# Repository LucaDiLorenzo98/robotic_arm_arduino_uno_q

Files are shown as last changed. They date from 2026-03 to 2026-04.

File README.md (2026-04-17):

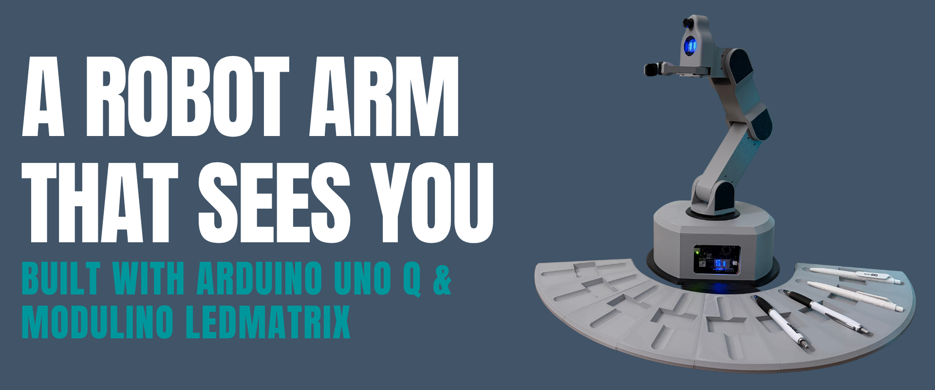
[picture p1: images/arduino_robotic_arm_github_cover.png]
Arduino Robotic Arm Cover


# A Robot Arm That Sees You — Built with Arduino UNO Q & Modulino LedMatrix

A robot arm that recognizes people and delivers gadgets to them — no buttons, no commands, just interaction. Built with the new Arduino UNO Q 4GB and the new Modulino LedMatrix, which gives the robot its friendly face. The arm runs on Feetech digital servo motors with a Waveshare control board, and a camera on the head handles the recognition. From high school tinkering to projects like this — this is what Arduino made possible for me.

---

## Assembly Tutorial

<div align="center">
  <a href="https://www.youtube.com/watch?v=Ro49ItYjisA" target="_blank">
    Assembly Tutorial
  </a>
</div>

---

## Required Hardware

| Component | Details |
|---|---|
| **Arduino UNO Q** | Main board (MPU + MCU, onboard LED matrix 8×13) |
| **4× servo STS3215** | Half-duplex serial bus, IDs 1–4 |
| **Standard PWM servo** | Gripper on digital pin **D9** |
| **2× pressure sensor** | Analog on **A0** and **A1** |
| **Modulino LED Matrix** | Head display 12×8 (optional but recommended) |
| **Half-duplex adapter** | To connect STS3215 to UNO Q Serial port |

### Pin Scheme

```
D9         → gripper servo signal (PWM)
A0         → pressure sensor 1
A1         → pressure sensor 2
Serial (pins 0 & 1) → STS3215 bus (1 Mbit/s, half-duplex)
Modulino Quick Connector → Modulino LED Matrix (head, I2C)
```

---

## Electrical Schematic

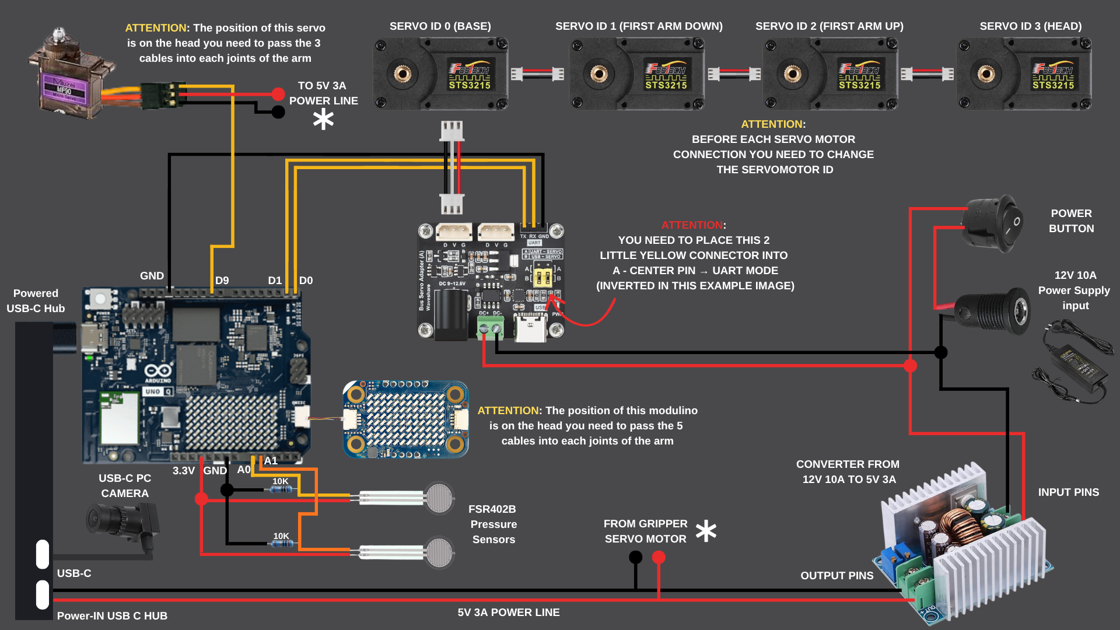
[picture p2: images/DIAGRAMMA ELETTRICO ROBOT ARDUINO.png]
Electrical Schematic Diagram


The schematic above shows the complete electrical connections for the robot, including:
- **Arduino UNO Q** as the main control board
- **STS3215 servo motors** (4×) connected via the Waveshare driver board on the half-duplex serial bus at 1 Mbit/s
- **PWM servo** for gripper control on digital pin D9
- **Pressure sensors** (2×) on analog inputs A0 and A1
- **Power distribution** from a 12V 10A power supply
- **Modulino LED Matrix** connected via I2C on the Quick Connector for the head display

---

## Bill of Materials (Non-Printed Components)

| Component | Qty | Link |
|---|---|---|
| Arduino UNO Q 4GB RAM | 1 | [Buy on Arduino Store](https://store.arduino.cc/products/uno-q-4gb?variant=56485750473079) |
| Modulino LED Matrix | 1 | [Buy on Arduino Store USA](https://store-usa.arduino.cc/products/modulino-led-matrix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) |
| Feetech Digital STS3215 Servo Motors | 4 | [Buy on AliExpress](https://it.aliexpress.com/item/1005009271910382.html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) |
| Waveshare Serial Bus Servo Driver Board | 1 | [Buy on Amazon](https://www.amazon.it/dp/B0CJ6TP3TP?ref=ppx_yo2ov_dt_b_fed_asin_title) |
| Ball Bearing | 1 | [Buy on AliExpress](https://it.aliexpress.com/item/1005009736872307.html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) |
| Pressure Sensors | 2 | [Buy on AliExpress](https://it.aliexpress.com/item/1005009958997279.html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) |
| 12V 10A Power Supply | 1 | [Buy on Amazon](https://www.amazon.it/-/en/dp/B0D1VHNF9R?ref_=ppx_hzsearch_conn_dt_b_fed_asin_title_1) |
| DC Converter 12V to 5V 3A | 1 | [Buy on Amazon](https://www.amazon.it/dp/B08MWK3VKC?ref=ppx_yo2ov_dt_b_fed_asin_title) |
| Lemorele USB-C Docking Station | 1 | [Buy on Amazon](https://www.amazon.it/dp/B08GM2H1Q2?ref=ppx_yo2ov_dt_b_fed_asin_title&th=1) |
| Micro Servo Metal Gear 90° | 1 | [Buy on Amazon](https://www.amazon.it/dp/B0C38H8TBY?ref=ppx_yo2ov_dt_b_fed_asin_title&th=1) |
| USB Camera | 1 | [Buy on Amazon](https://www.amazon.it/dp/B0DNT67G7C?ref=ppx_yo2ov_dt_b_fed_asin_title) |
| Resistors Kit | 1 | Common electronics store |
| M3 Screws | Various | Common hardware store |
| Power Supply Wires | As needed | Common hardware store |
| Power Cable 18/16 AWG | 1 roll | Common hardware store |
| Circular Power Connector | 1 | Common electronics store |
| Circular Switch 2-Pin | 1 | Common electronics store |
| Threaded Inserts (3×4, 5×5 mm) | Set | [Buy on AliExpress](https://it.aliexpress.com/w/wholesale-threaded-inserts-m3.html) |

---

## 3D Files and Printing

3D files are available in the **`3d_models/`** folder:

- **`models.3mf`** – Complete project with all components **already oriented and ready to print** (recommended)
- **Individual STL files** – For those who prefer manual slicing

### Recommended Materials

| Component | Material | Notes |
|---|---|---|
| Arm structure, base, covers | **PETG HF** | Resistant, good rigidity, high temperatures |
| Gripper components (gripper_*) | **TPU 95A** | Elastic, shock-absorbing, suitable for repeated movements |

---

## ⚠️ Pre-Assembly: Servo ID Configuration (MANDATORY)

> **This step must be completed BEFORE assembling the robot.**
> If you skip it, the firmware won't be able to address the servos and nothing will work.

Each STS3215 servo ships from the factory with **ID 1**. Since all 4 motors share the same serial bus, each one must have a unique ID (1, 2, 3, 4) before they are wired together. You must configure them **one at a time**, while they are still unassembled.

### What you need

- The Waveshare Serial Bus Servo Driver Board
- One STS3215 servo connected to it (just one at a time)
- A USB cable to power/connect the board
- The sketch `sc_servo_change_id/sc_servo_change_id.ino` from this repo

### Procedure (repeat for each of the 4 servos)

1. **Connect only one servo** to the Waveshare board. Do not connect the others.
2. Open `sc_servo_change_id/sc_servo_change_id.ino` in Arduino IDE.
3. At the top of the sketch, set the two ID variables:

   ```cpp
   int idAttuale = 1;  // Factory default for a brand-new servo is always 1
   int idNuovo   = 1;  // The ID you want to assign to this servo
   ```

   | Servo | `idAttuale` | `idNuovo` |
   |---|---|---|
   | 1st servo | `1` | `1` |
   | 2nd servo | `1` | `2` |
   | 3rd servo | `1` | `3` |
   | 4th servo | `1` | `4` |

4. Upload and run the sketch. Open the **Serial Monitor** at 115200 baud.
5. If successful, you'll see:
   ```
   SUCCESSO! Il servo ora ha l'ID: X
   Ora puoi scollegarlo e passare al prossimo.
   ```
6. **Disconnect** the servo, connect the next one, update `idNuovo` in the sketch, and repeat.

> If the Serial Monitor shows `ERRORE: Servo non rilevato`, check the 12V power supply to the Waveshare board and verify the connection to the servo. Make sure `idAttuale` matches the servo's current ID (new servos always start at 1).

Once all 4 servos have their IDs assigned, you can proceed with mechanical assembly and wire them all together on the bus.

---

## Arduino Libraries to Install

Open **Tools → Manage Libraries** in Arduino IDE / Arduino Lab and install:

| Library | Min version | Notes |
|---|---|---|
| `Arduino_RouterBridge` | latest | Bridge MCU↔MPU |
| `SCServo` | latest | STS3215 control |
| `Arduino_LED_Matrix` | latest | Onboard UNO Q matrix |
| `ArduinoGraphics` | latest | LED Matrix dependency |
| `Modulino` or `Arduino_Modulino` | latest | For LED head (optional) |

---

## Python Dependencies

The project runs on the MPU (Linux) side of UNO Q via Arduino Python environment. No manual installation required: the dependencies (`arduino.app_utils`, `arduino.app_bricks.video_objectdetection`) are part of the Arduino SDK.

Only standard libraries are used: `datetime`, `time`, `threading`, `math`, `os`, `sys`, `functools`.

---

## How to Upload and Run

1. Open **Arduino Lab** (or Arduino IDE with UNO Q support).
2. Upload the sketch `sketch/sketch.ino` to the board.
3. The Python app `python/main.py` is automatically started by the Arduino environment on the MPU side.
4. Real-time logs are also written to `python/robot.log` (with timestamp).

---

## Robot Setup (First Power-On or Reset)

On startup, the robot automatically enters **setup mode**. The onboard matrix shows the current step (**S1**, **S2**, **S3**).

STS3215 servo torque is **disabled**: you can move the arm freely by hand.

### Step S1 – HOME Position

1. Move the arm by hand to the HOME position (upright, centered).
2. Hold it steady for **5 seconds** → the matrix blinks the step number during the countdown.
3. Once captured, the robot nods with servo 4 to confirm, then moves to S2.

### Step S2 – Slot Positions (up to 9)

1. Move the arm toward the **first slot** (where the pens are).
2. Hold it steady for **5 seconds** → slot captured, the robot returns to HOME and nods.
3. Repeat for each following slot (up to a maximum of **9 slots**).
4. After the last slot, the robot returns to HOME and shows **S3** → setup complete.

> The system ignores small vibrations and microadjustments: it waits for real manual movement before starting the countdown.

### Step S3 – Setup Complete

The robot enters **detect** state and is operational.

---

## Normal Operation

```
setup → detect → grab → delivery → (face detected) → release → detect → ...
```

| State | What it does | Display |
|---|---|---|
| **detect** | Awaits face detection; idle animation on servos | Blinking eyes, matrix **D** |
| **grab** | Collects pen from current slot (base rotation → descent → gripper close → HOME) | Fixed eyes, matrix **G** |
| **delivery_waiting** | Waits at HOME with pen in hand for a face to arrive | Fixed eyes |
| **release** | Detects face → shows hearts, opens gripper, delivers pen | Heart eyes, matrix **R** |

### Grab Cycle Details

1. Base rotation toward slot
2. Partial descent (50% travel)
3. Gripper soft open (~165°)
4. Full descent to slot
5. Gripper close (180° × 3 attempts)
6. Return to HOME
7. Wait for face for delivery

Pressure sensors on A0/A1 are read before and after gripper close (log: `[GRAB][PRESSURE]`).

### Idle Animation

When in **detect** state, the arm performs smooth sinusoidal oscillation on all 4 servos (period 10 s), then returns to HOME and stops for 30 s before repeating.

---

## Error Codes (Onboard Display)

| Display | Code | Cause |
|---|---|---|
| `ER1` | Setup pose unavailable | One or more STS3215 don't respond to ping during setup |
| `ER2` | Grab slot not configured | Grab requested but no slot configured |
| `ER3` | STS move failed | STS movement command failed |
| `ER4` | *(deprecated)* | Matrix unavailable |
| `ER5` | Pressure read failed | Pressure sensor read error |

---

## Logging and Debug

- Logs are written to both console and `python/robot.log` (each line has timestamp `HH:MM:SS.mmm`).
- You can set a custom path with the `ROBOT_LOG_PATH` environment variable.
- STS3215 logs show ping and position of each servo on startup (`[STS3215] Check servo`).

---

## Project Structure

```
sketch/
  sketch.ino         # Arduino firmware (MCU): servo, STS3215, LED matrix, Bridge
python/
  main.py            # Python app (MPU): face detection, state machine, idle animation
  robot.log          # Runtime log (auto-generated)
images/
  arduino_robotic_arm_github_cover.png
```

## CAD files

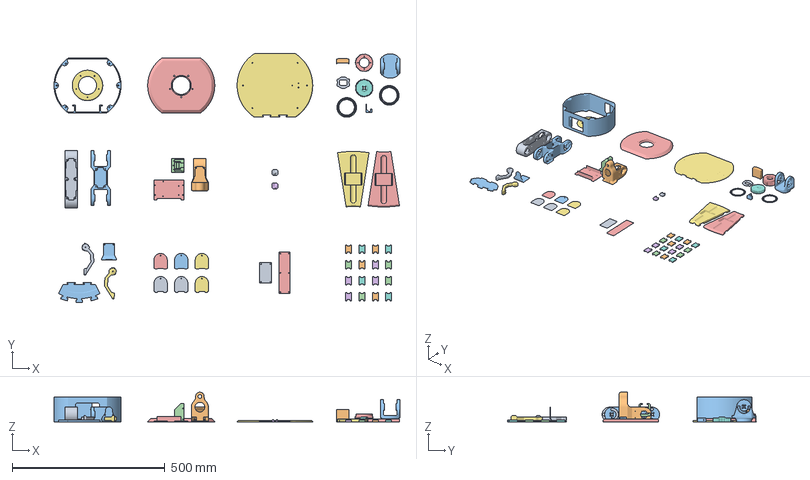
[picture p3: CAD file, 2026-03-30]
3d_models/arduino_robot_gadget_3d_model.3mf
1134.3 x 814.8 x 97.2 mm
gripper_pen_threated_pad_dx.stl
third_arm.stl
third_arm_cover.stl
servo_base_support.stl
arduino_support_shield.stl
gripper_pen_threated_pad_sx.stl
free_gripper.stl
pen_holder_joint.stl x 16
servo_gripper.stl
holders_base_connector.stl
first_arm_cover.stl
joint_cover.stl x 6
second_arm_cover.stl
pen_holder.stl x 2
first_arm_joint.stl
second_arm.stl
first_arm_gear.stl
base_cover.stl
servo_gear.stl
first_arm.stl
outer_spacer.stl x 2
base_side.stl
base_top.stl
inner_spacer.stl x 2
bearing_cover.stl
modulino_led_matrix_support.stl
servo_support_enforcer.stl
third_arm_gear_support.stl

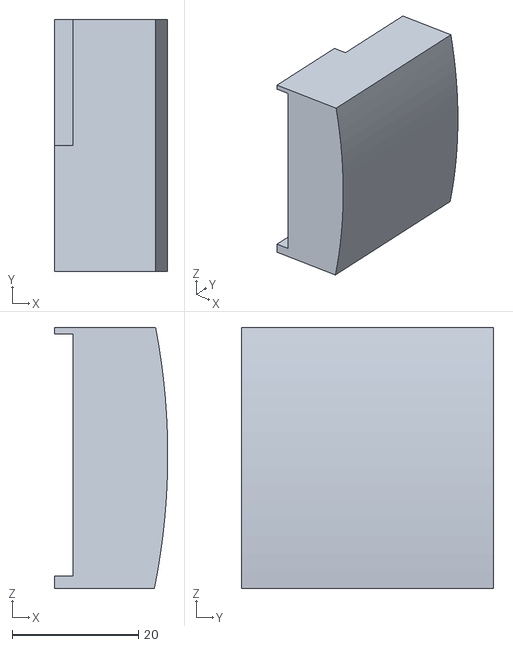
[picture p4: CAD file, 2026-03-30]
3d_models/STLs/servo_support_enforcer.stl
18.0 x 40.0 x 41.4

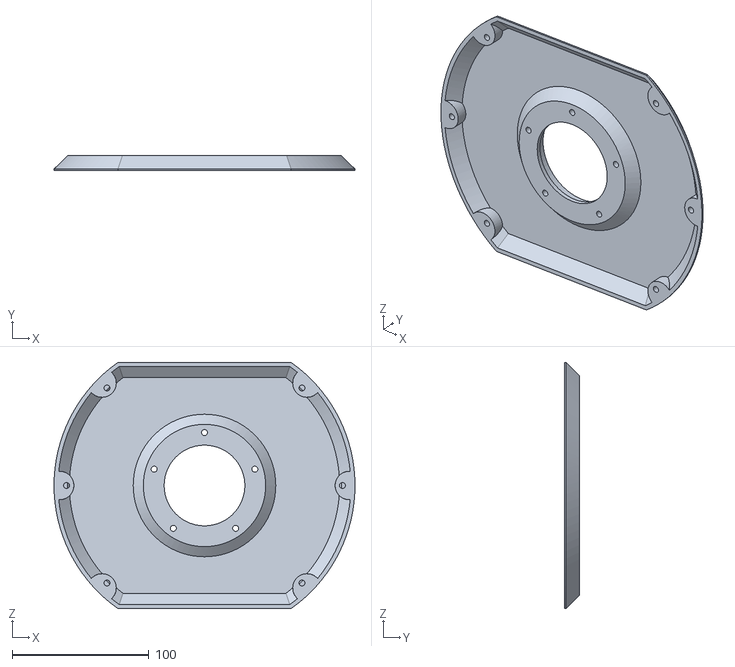
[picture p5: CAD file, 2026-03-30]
3d_models/STLs/base_top.stl
220.0 x 11.2 x 180.0

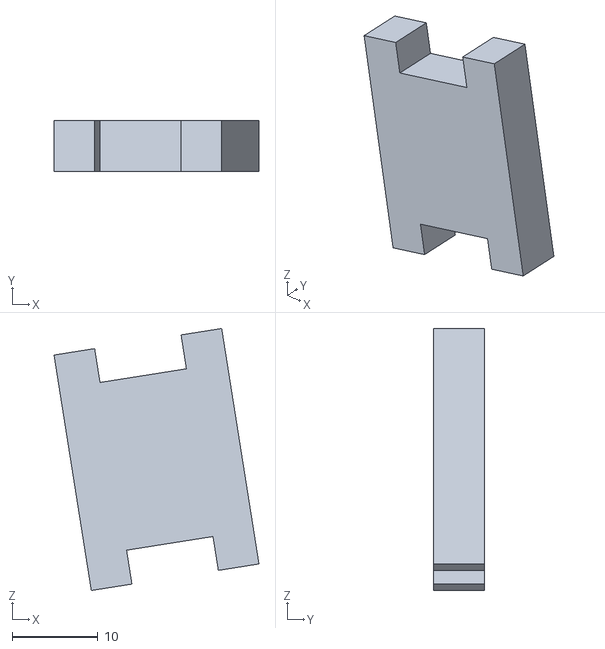
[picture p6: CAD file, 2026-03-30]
3d_models/STLs/pen_holder_joint.stl
23.9 x 5.90 x 30.6

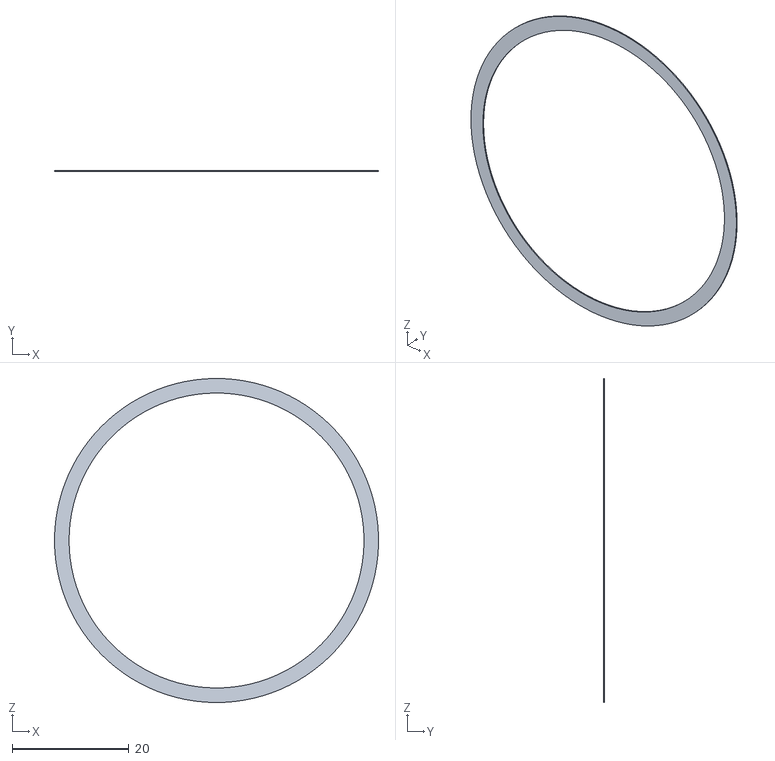
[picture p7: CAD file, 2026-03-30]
3d_models/STLs/inner_spacer.stl
55.6 x 0.2 x 55.6

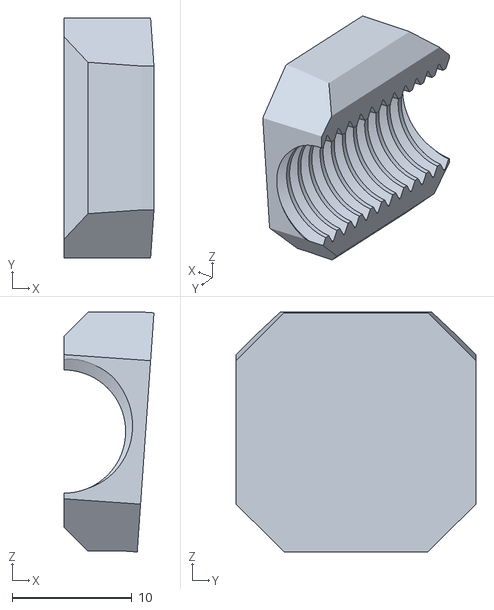
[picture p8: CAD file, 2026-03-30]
3d_models/STLs/gripper_pen_threated_pad_dx.stl
7.50 x 20.0 x 20.0

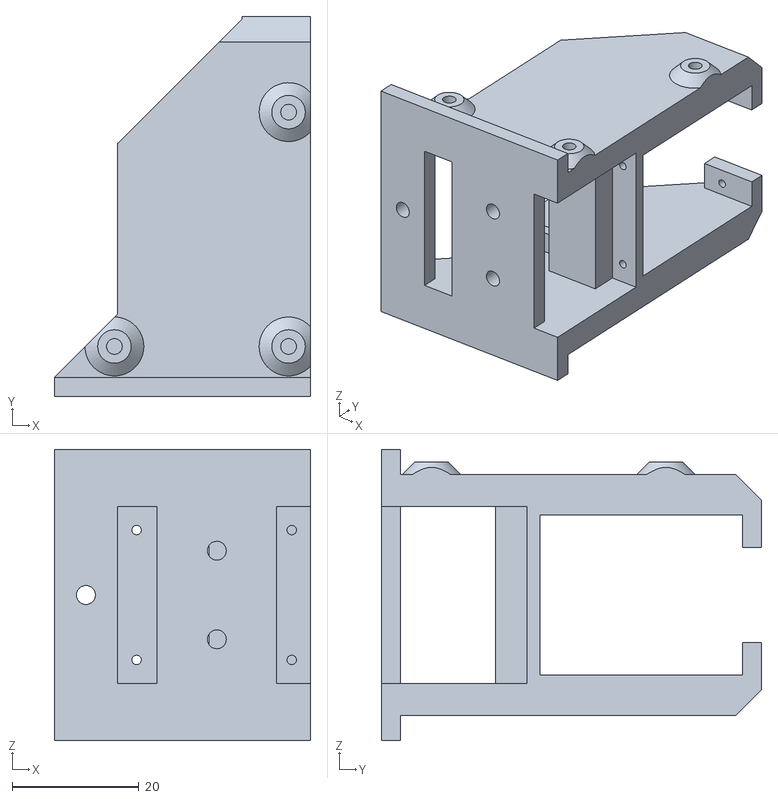
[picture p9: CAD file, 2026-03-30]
3d_models/STLs/servo_base_support.stl
40.5 x 60.0 x 46.0

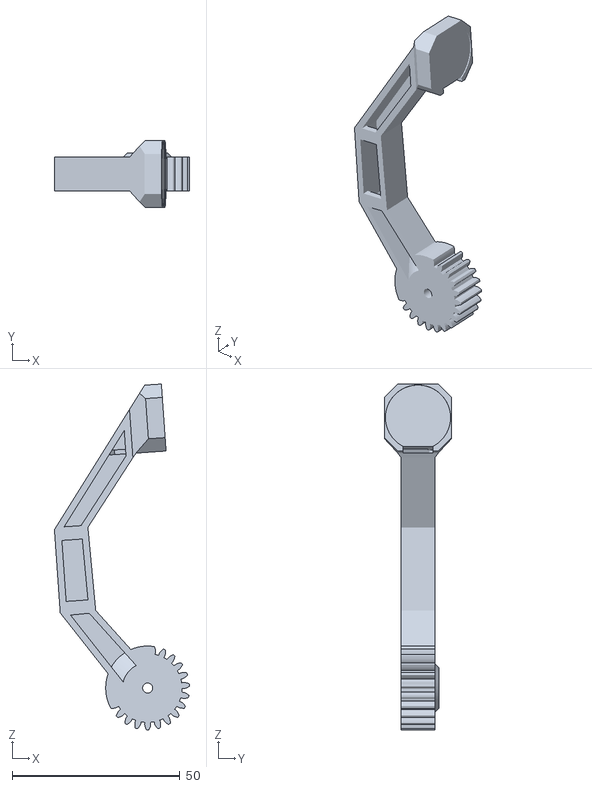
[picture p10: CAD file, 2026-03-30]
3d_models/STLs/free_gripper.stl
40.2 x 20.0 x 103.0

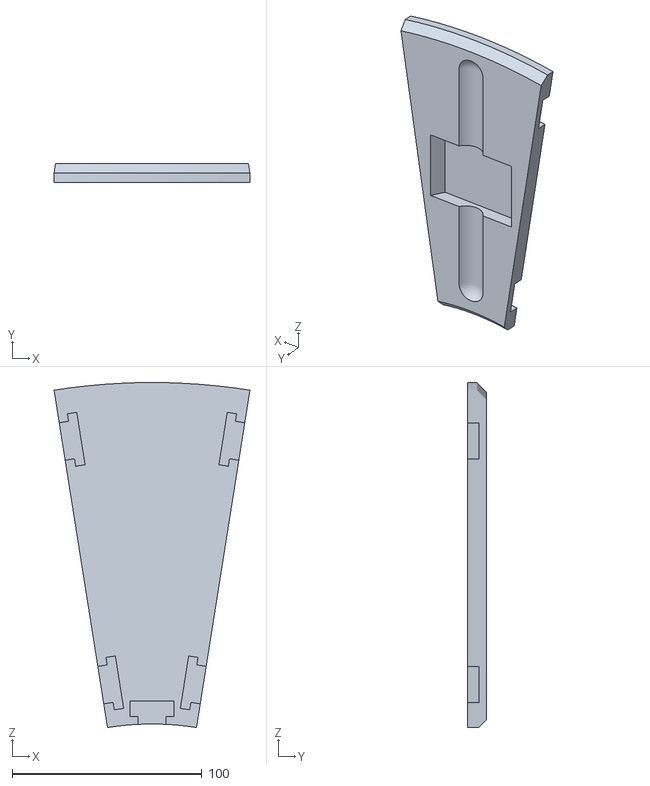
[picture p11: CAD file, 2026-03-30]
3d_models/STLs/pen_holder.stl
103.2 x 10.0 x 181.8

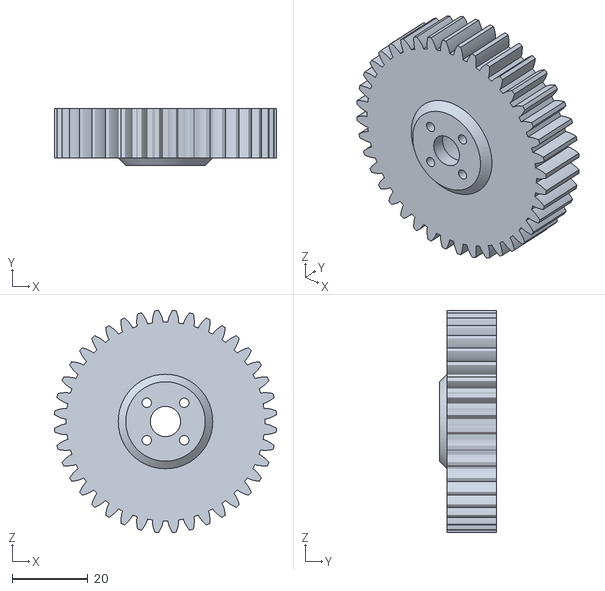
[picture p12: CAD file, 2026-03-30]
3d_models/STLs/servo_gear.stl
58.7 x 15.0 x 58.7

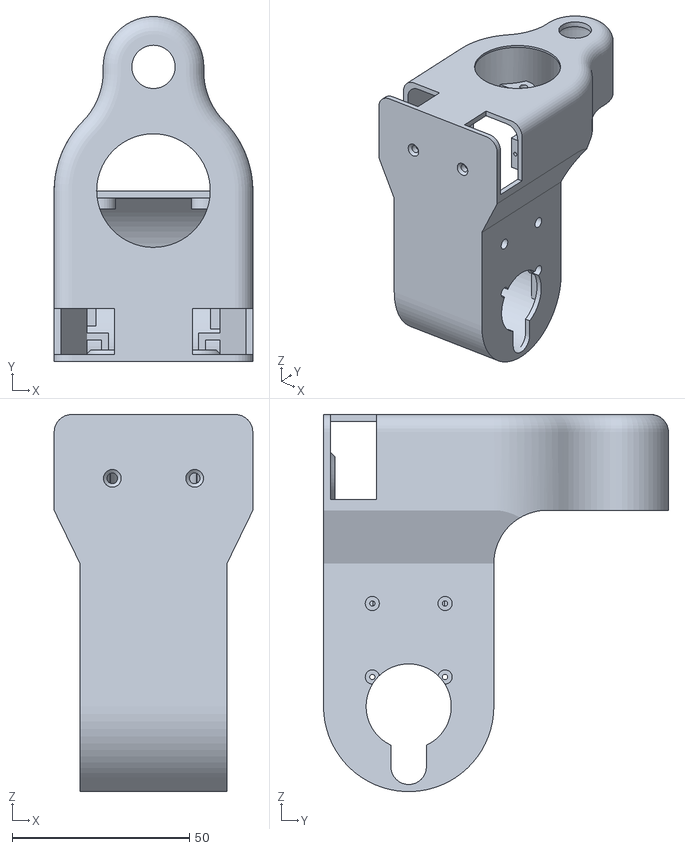
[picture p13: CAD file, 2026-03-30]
3d_models/STLs/third_arm.stl
56.0 x 97.2 x 106.2

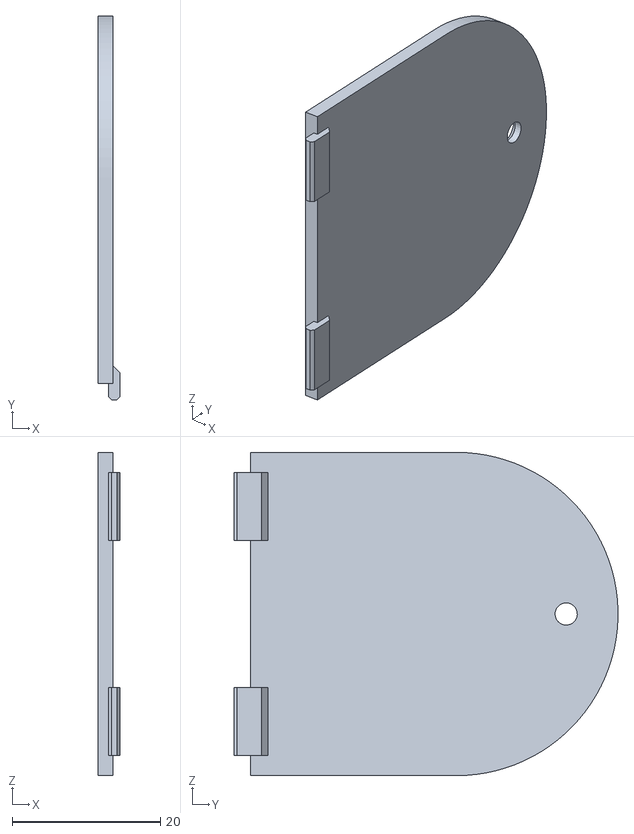
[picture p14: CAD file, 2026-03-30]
3d_models/STLs/joint_cover.stl
2.90 x 51.8 x 43.6

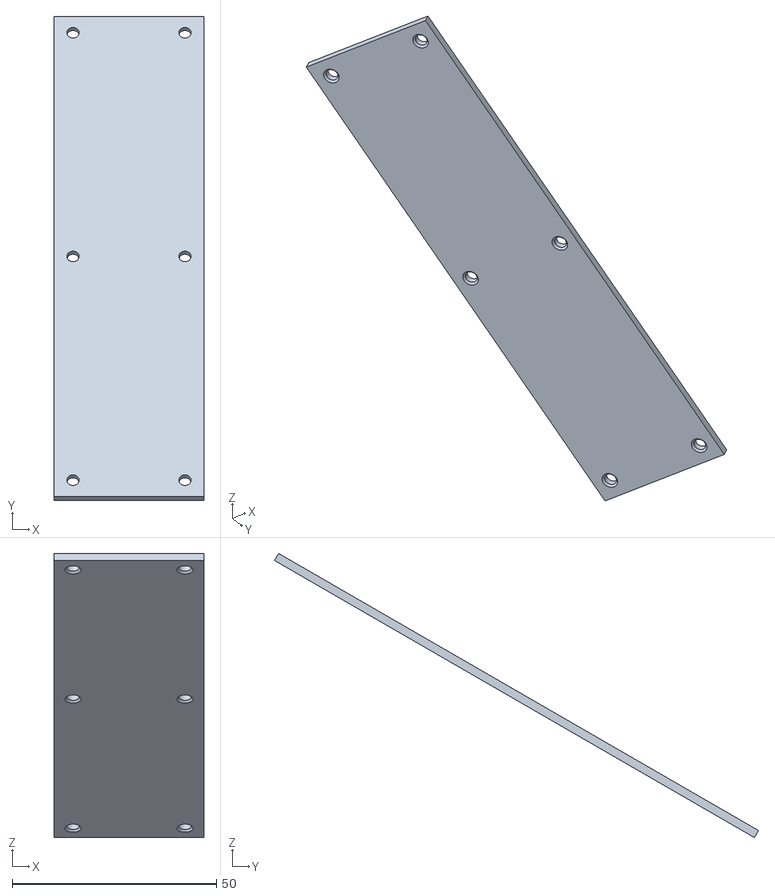
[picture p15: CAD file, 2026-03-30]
3d_models/STLs/first_arm_cover.stl
36.6 x 118.4 x 69.5

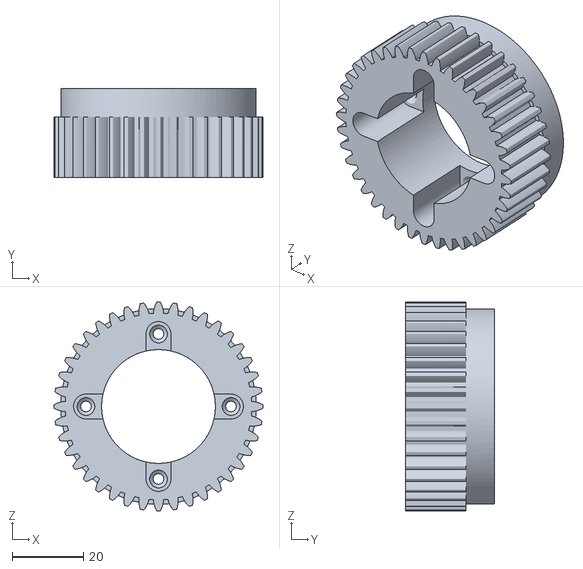
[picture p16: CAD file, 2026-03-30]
3d_models/STLs/first_arm_gear.stl
58.8 x 25.0 x 58.8

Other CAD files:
3d_models/STLs/gripper_pen_threated_pad_sx.stl
3d_models/STLs/third_arm_cover.stl
3d_models/STLs/outer_spacer.stl
3d_models/STLs/bearing_cover.stl
3d_models/STLs/arduino_support_shield.stl
3d_models/STLs/base_cover.stl
3d_models/STLs/base_side.stl
3d_models/STLs/first_arm.stl
3d_models/STLs/first_arm_joint.stl
3d_models/STLs/holders_base_connector.stl
3d_models/STLs/modulino_led_matrix_support.stl
3d_models/STLs/second_arm.stl
3d_models/STLs/second_arm_cover.stl
3d_models/STLs/servo_gripper.stl
3d_models/STLs/third_arm_gear_support.stl

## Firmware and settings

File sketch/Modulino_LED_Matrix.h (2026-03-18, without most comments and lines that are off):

#pragma once
#include "Arduino.h"
#include "Wire.h"
#if __has_include("ArduinoGraphics.h")
#include <ArduinoGraphics.h>
#define MATRIX_WITH_ARDUINOGRAPHICS
#endif
#if defined(ARDUINO_UNOR4_WIFI) || defined(ARDUINO_NANO_R4) || defined(ARDUINO_UNO_Q)
#define DEFAULT_WIRE Wire1
#else
#define DEFAULT_WIRE Wire
#endif
constexpr uint8_t NUM_LEDS = 96;
constexpr uint8_t DEFAULT_ADDRESS = 0x39;
constexpr uint8_t GRAYSCALE_FRAME_SIZE = 48;
constexpr uint8_t MONOCHROMATIC_FRAME_SIZE = 12;
constexpr size_t DURATION_SIZE = sizeof(uint32_t);
constexpr size_t MONOCHROMATIC_ANIMATION_FRAME_SIZE = MONOCHROMATIC_FRAME_SIZE + DURATION_SIZE;
constexpr char GRAYSCALE_IDENTIFIER[] = "GS4";
constexpr char MONOCHROMATIC_IDENTIFIER[] = "MON";
constexpr uint8_t MODE_IDENTIFIER_SIZE = 3;
enum class DisplayMode {
    MonochromaticVertical,
    MonochromaticHorizontal,
    Grayscale,
    Default = MonochromaticVertical
};
class ModulinoLEDMatrix
#ifdef MATRIX_WITH_ARDUINOGRAPHICS
    : public ArduinoGraphics
#endif
     {
public:
    ModulinoLEDMatrix(uint8_t address = DEFAULT_ADDRESS, HardwareI2C& wire = DEFAULT_WIRE, DisplayMode mode = DisplayMode::Default)
    #ifdef MATRIX_WITH_ARDUINOGRAPHICS
        : ArduinoGraphics(canvasWidth, canvasHeight)
    #endif
    {
        _address = address;
        _wire = &wire;
        _mode = mode;
    }
    ModulinoLEDMatrix(HardwareI2C& wire, uint8_t address = DEFAULT_ADDRESS, DisplayMode mode = DisplayMode::Default)
    #ifdef MATRIX_WITH_ARDUINOGRAPHICS
        : ArduinoGraphics(canvasWidth, canvasHeight)
    #endif
    {
        _address = address;
        _wire = &wire;
        _mode = mode;
    }
    void setMode(DisplayMode mode){
        _mode = mode;
        sendMode();
    }
    int begin() {
        if (_initialized) {
            return 1; // Already initialized
        }
        _wire->begin();
        _initialized = true;
        sendMode();
        return 1;
    }
    void nextFrame() {
        renderFrame();
        _currentFrameNumber = (_currentFrameNumber + 1) % _framesCount;
        if(_currentFrameNumber == 0){
            _sequenceDone = true;
            if(_sequenceDoneCallBack != nullptr){
                _sequenceDoneCallBack();
            }
        }
    }
    template<size_t N>
    void setFrame(const uint32_t(&buffer)[N]){
        size_t frameSize = expectedFrameSize();
        uint8_t data[frameSize];
        convert32to8bit(buffer, N, data, frameSize);
        prepareFrame(data);
        sendFrame(data, frameSize);
    }
    template<size_t N>
    void setFrame(const uint8_t(&buffer)[N]){
        size_t frameSize = expectedFrameSize();
        uint8_t data[frameSize];
        auto length = (N < frameSize) ? N : frameSize;
        memcpy(data, buffer, length);
        prepareFrame(data);
        sendFrame(data, length);
    }
    void renderFrame(uint32_t frameNumber){
        _currentFrameNumber = frameNumber % _framesCount;
        renderFrame();
    }
    void renderFrame(){
        size_t frameSize = expectedFrameSize();
        uint8_t data[frameSize];
        getCurrentFrameData(data);
        setCurrentDuration();
        prepareFrame(data);
        sendFrame(data, frameSize);
    }
    void play(bool looping = false){
        _loop = looping;
        _sequenceDone = false;
        do {
            nextFrame();
            delay(_duration);
            if (_loop && _sequenceDone) {
                _sequenceDone = false;
            }
        } while (_sequenceDone == false);
    }
    uint32_t getCurrentDuration() const {
        return _duration;
    }
    uint32_t getCurrentFrameNumber() const {
        return _currentFrameNumber;
    }
    uint32_t getFrameCount() const {
        return _framesCount;
    }
    void setSequence(const uint8_t* frames, size_t bytes, bool is32Bit = false) {
        _currentFrameNumber = 0;
        _frames = frames;
        size_t frameSize = expectedFrameSize();
        _framesCount = bytes / (frameSize + 4);
        _framesAre32Bit = is32Bit;
    }
    template<size_t N, size_t M>
    void setSequence(const uint32_t (&frames)[N][M]) {
        setSequence((const uint8_t*)frames, sizeof(frames), true);
    }
    template<size_t N, size_t M>
    void setSequence(const uint8_t (&frames)[N][M]) {
        setSequence((const uint8_t*)frames, sizeof(frames));
    }
    template<size_t N, size_t M>
    void setSequence(const uint8_t (&frames)[N][M], size_t usedBytes) {
        setSequence((const uint8_t*)frames, usedBytes);
    }
    void setSequenceDoneCallback(voidFuncPtr callBack){
        _sequenceDoneCallBack = callBack;
    }
    void clear() {
        const uint32_t fullOff[] = {
            0x00000000,
            0x00000000,
            0x00000000
        };
        setFrame(fullOff);
        #ifdef MATRIX_WITH_ARDUINOGRAPHICS
        memset(_canvasBuffer, 0, sizeof(_canvasBuffer));
        #endif
    }
#ifdef MATRIX_WITH_ARDUINOGRAPHICS
    template<size_t N, size_t M>
    void loadPixelsToFrameBuffer(const uint8_t (&pixelData)[N][M], uint8_t* outputFrameBuffer) {
        memset(outputFrameBuffer, 0, (N * M) / 8);
        const uint8_t* pixelDataFlat = &pixelData[0][0];
        size_t index;
        for (size_t i = 0; i < (N * M); i++) {
             if (pixelDataFlat[i]) {
                if (_mode == DisplayMode::MonochromaticHorizontal) {
                    outputFrameBuffer[i / 8] |= (1 << (7 - (i % 8)));
                } else if (_mode == DisplayMode::MonochromaticVertical) {
                    size_t row = i / M;
                    size_t col = i % M;
                    index = col * N + row;
                    outputFrameBuffer[index / 8] |= (1 << (index % 8));
                } else {
                    return; // Unsupported mode for this function
                }
            }
        }
    }
    void renderCanvas(){
        loadPixelsToFrameBuffer(_canvasBuffer, _graphicsFrameHolder);
        setFrame(_graphicsFrameHolder);
    };
    virtual void set(int x, int y, uint8_t r, uint8_t g, uint8_t b) override {
      if (y >= canvasHeight || x >= canvasWidth || y < 0 || x < 0) {
        return;
      }
      _canvasBuffer[y][x] = (r | g | b) > 0 ? 1 : 0;
    }
    void endText(int scrollDirection = NO_SCROLL) {
      ArduinoGraphics::endText(scrollDirection);
      renderCanvas();
    }
    void endDraw() override {
        ArduinoGraphics::endDraw();
        if (!captureAnimation) {
            renderCanvas();
            return;
        }
        if (captureAnimationFrameRemainingBytes >= MONOCHROMATIC_ANIMATION_FRAME_SIZE) {
            loadPixelsToFrameBuffer(_canvasBuffer, captureAnimationFrame);
            uint32_t speed = _textScrollSpeed;
            memcpy(captureAnimationFrame + MONOCHROMATIC_FRAME_SIZE, &speed, DURATION_SIZE);
            captureAnimationFrame += MONOCHROMATIC_ANIMATION_FRAME_SIZE;
            captureAnimationFrameRemainingBytes -= MONOCHROMATIC_ANIMATION_FRAME_SIZE;
        }
    }
    template <size_t N, size_t M>
    void endTextAnimation(int scrollDirection, uint8_t (&frames)[N][M], uint32_t& bytesUsed) {
      captureAnimationFrame = &frames[0][0];
      captureAnimationFrameRemainingBytes = sizeof(frames);
      captureAnimation = true;
      ArduinoGraphics::textScrollSpeed(0);
      ArduinoGraphics::endText(scrollDirection);
      ArduinoGraphics::textScrollSpeed(_textScrollSpeed);
      captureAnimation = false;
      bytesUsed = sizeof(frames) - captureAnimationFrameRemainingBytes;
    }
    void textScrollSpeed(unsigned long speed) override {
      ArduinoGraphics::textScrollSpeed(speed);
      _textScrollSpeed = speed;
    }
  private:
    uint8_t _graphicsFrameHolder[MONOCHROMATIC_FRAME_SIZE]; // 12 bytes
    uint8_t* captureAnimationFrame = nullptr; // pointer to next frame to write
    uint32_t captureAnimationFrameRemainingBytes = 0; // bytes remaining in buffer
    bool captureAnimation = false;
    static const byte canvasWidth = 12;
    static const byte canvasHeight = 8;
    uint8_t _canvasBuffer[canvasHeight][canvasWidth] = {{0}};
    unsigned long _textScrollSpeed = 100;
#endif
private:
    void sendFrame(uint8_t* data, size_t length) {
        if(!_initialized) return;
        _wire->beginTransmission(_address);
        _wire->write(data, length);
        _wire->endTransmission();
    }
    void setCurrentDuration(){
        size_t frameSize = expectedFrameSize();
        size_t durationSize = sizeof(_duration);
        auto frameOffset = _currentFrameNumber * (frameSize + durationSize);
        auto durationOffset = frameOffset + frameSize;
        memcpy(&_duration, _frames + durationOffset, durationSize);
    }
    void getCurrentFrameData(uint8_t* data) {
        size_t frameSize = expectedFrameSize();
        size_t durationSize = sizeof(_duration);
        auto frameOffset = _currentFrameNumber * (frameSize + durationSize);
        if (_framesAre32Bit) {
            const uint32_t* target = reinterpret_cast<const uint32_t*>(_frames + frameOffset);
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

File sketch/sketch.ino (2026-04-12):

#include <Arduino_RouterBridge.h>
#include <Wire.h>
#include <Servo.h>
#include <SCServo.h>
#include <Arduino_LED_Matrix.h>
#ifdef endTextAnimation
#undef endTextAnimation
#endif
#ifdef beginTextAnimation
#undef beginTextAnimation
#endif
#include <ArduinoGraphics.h>
#include "Modulino_LED_Matrix.h"
#if __has_include(<Modulino.h>)
#include <Modulino.h>
#define HAS_MODULINO_CORE 1
#elif __has_include(<Arduino_Modulino.h>)
#include <Arduino_Modulino.h>
#define HAS_MODULINO_CORE 1
#else
#define HAS_MODULINO_CORE 0
#endif

#define SERVO_PIN 9
#define PRESSURE_PIN_A0 A0
#define PRESSURE_PIN_A1 A1

Servo servo;
int lastServoAngle = 180;  // track last commanded angle (default: closed)
SMS_STS sts;  // STS3215 serial bus controller

Arduino_LED_Matrix coreMatrix;
bool core_matrix_ready = false;

int led_matrix_intensity = 3;  // 0..15, API compatibility

// Head matrix (Modulino LED Matrix). Logical coordinates: x=0..11, y=0..7.
ModulinoLEDMatrix headMatrix;
bool head_matrix_ready = false;
volatile int head_state_code = 3; // 0=detect,1=grab,2=release,3=setup
unsigned long head_last_blink_ms = 0;
bool head_blink_closed = false;
unsigned long head_last_tick_ms = 0;
int head_last_render_state = -1;
bool head_last_render_blink = false;

static inline int _clamp_i(int v, int lo, int hi) { return v < lo ? lo : (v > hi ? hi : v); }

// Head matrix orientation mapping.
static void _head_point(int x, int y) {
  // No rotation (direct mapping). If still rotated, we can switch to 90° mapping.
  x = _clamp_i(x, 0, 11);
  y = _clamp_i(y, 0, 7);
  headMatrix.point(x, y);
}

static void _head_rect(int x, int y, int w, int h) {
  for (int yy = y; yy < (y + h); yy++) {
    for (int xx = x; xx < (x + w); xx++) {
      _head_point(xx, yy);
    }
  }
}

static void _head_clear_draw() {
  headMatrix.clear();
  headMatrix.beginDraw();
  headMatrix.stroke(0xFFFFFF);
  headMatrix.fill(0xFFFFFF);
}

static void _head_end_draw() { headMatrix.endDraw(); }

static void _head_capsule_filled(int x, int y, int w, int h) {
  // Draw a filled vertical capsule using pixel math (rect + 2 semicircles).
  if (w < 1 || h < 1) return;
  int r = w / 2;
  if (r < 1) r = 1;
  int cx = x + (w - 1) / 2;
  int cy_top = y + r;
  int cy_bot = y + h - 1 - r;
  for (int yy = y; yy < (y + h); yy++) {
    for (int xx = x; xx < (x + w); xx++) {
      bool inside = false;
      if (yy >= (y + r) && yy <= (y + h - 1 - r)) {
        inside = true; // middle rectangle
      } else if (yy < (y + r)) {
        int dx = xx - cx;
        int dy = yy - cy_top;
        inside = (dx * dx + dy * dy) <= (r * r);
      } else {
        int dx = xx - cx;
        int dy = yy - cy_bot;
        inside = (dx * dx + dy * dy) <= (r * r);
      }
      if (inside) _head_point(xx, yy);
    }
  }
}

static void _head_draw_eyes_open() {
  // Vertical capsule eyes (filled)
  _head_capsule_filled(2, 1, 3, 6);
  _head_capsule_filled(7, 1, 3, 6);
}

static void _head_draw_eyes_blink() {
  // Thin blink line
  _head_rect(2, 4, 3, 1);
  _head_rect(7, 4, 3, 1);
}

static void _head_draw_eyes_grab() {
  // Focused eyes: same capsules
  _head_capsule_filled(2, 1, 3, 6);
  _head_capsule_filled(7, 1, 3, 6);
}

static void _head_draw_eyes_release() {
  // Happy eyes: bigger capsules
  _head_capsule_filled(1, 1, 4, 6);
  _head_capsule_filled(7, 1, 4, 6);
}

static void _head_draw_eyes_heart() {
  // Pixel-art hearts on 12x8 matrix.
  // Left heart (cols 0-4)
  _head_point(1, 1); _head_point(3, 1);
  _head_point(0, 2); _head_point(1, 2); _head_point(2, 2); _head_point(3, 2); _head_point(4, 2);
  _head_point(0, 3); _head_point(1, 3); _head_point(2, 3); _head_point(3, 3); _head_point(4, 3);
  _head_point(1, 4); _head_point(2, 4); _head_point(3, 4);
  _head_point(2, 5);
  // Right heart (cols 7-11)
  _head_point(8, 1); _head_point(10, 1);
  _head_point(7, 2); _head_point(8, 2); _head_point(9, 2); _head_point(10, 2); _head_point(11, 2);
  _head_point(7, 3); _head_point(8, 3); _head_point(9, 3); _head_point(10, 3); _head_point(11, 3);
  _head_point(8, 4); _head_point(9, 4); _head_point(10, 4);
  _head_point(9, 5);
}

static void _head_render_state(int state_code, bool blink_closed) {
  if (!head_matrix_ready) return;
  _head_clear_draw();
  if (state_code == 0) { // detect
    if (blink_closed) _head_draw_eyes_blink();
    else _head_draw_eyes_open();
  } else if (state_code == 1) { // grab
    _head_draw_eyes_grab();
  } else if (state_code == 2) { // release
    _head_draw_eyes_release();
  } else if (state_code == 4) { // heart eyes (delivery)
    _head_draw_eyes_heart();
  } else { // setup
    _head_draw_eyes_open();
    // No extra indicator pixels (avoid "stuck" top-right LED)
  }
  _head_end_draw();
}

static void _head_tick() {
  if (!head_matrix_ready) return;
  unsigned long now = millis();
  if (now - head_last_tick_ms < 60) return;
  head_last_tick_ms = now;

  if (head_state_code == 0 || head_state_code == 3) {
    if (now - head_last_blink_ms > 3500) {
      head_blink_closed = true;
      head_last_blink_ms = now;
    }
    if (head_blink_closed && (now - head_last_blink_ms > 160)) {
      head_blink_closed = false;
    }
    if (head_last_render_state != head_state_code || head_last_render_blink != head_blink_closed) {
      _head_render_state(head_state_code, head_blink_closed);
      head_last_render_state = head_state_code;
      head_last_render_blink = head_blink_closed;
    }
  }
}

// Helper: convert angle (0-180) to microseconds (500-2500).
int _angleToUs(int angle) {
  return map(angle, 0, 180, 500, 2500);
}

// Helper: attach servo and immediately restore last position (no 90° glitch).
void _safeAttach() {
  if (!servo.attached()) {
    servo.attach(SERVO_PIN, 500, 2500);
    servo.writeMicroseconds(_angleToUs(lastServoAngle));
  }
}

// Called from Python when a face is detected. Angle in degrees (0-180).
// Ramps in 1° steps to reduce vibration and oscillation.
int move_servo(int angle) {
  if (angle < 0) angle = 0;
  if (angle > 180) angle = 180;
  _safeAttach();
  int step = (angle > lastServoAngle) ? 1 : -1;
  while (lastServoAngle != angle) {
    lastServoAngle += step;
    servo.writeMicroseconds(_angleToUs(lastServoAngle));
    delay(8);  // ~120°/s — abbassa per movimenti più lenti, alza per più veloci
  }
  return 1;
}

int gripper_hold(int hold) {
  if (hold) {
    _safeAttach();
  }
  // Never detach — servo always holds position
  return 1;
}

// Pressure sensors: analog read (0-1023). Exposed via Bridge.
int read_pressure_a0() {
  return analogRead(PRESSURE_PIN_A0);
}

int read_pressure_a1() {
  return analogRead(PRESSURE_PIN_A1);
}

// ---- STS3215 servo bus (SCServo library) ----
int sts_ping(int id) {
  return sts.Ping((u8)id);
}

int sts_read_pos(int id) {
  return sts.ReadPos((u8)id);
}

int sts_move_pos(int id, int position, int speed, int acc) {
  return sts.WritePosEx((u8)id, (s16)position, (u16)speed, (u8)acc);
}

int sts_torque_enable(int id, int enable) {
  u8 en = enable ? 1 : 0;
  return sts.EnableTorque((u8)id, en);
}

int led_matrix_available() {
  return (head_matrix_ready || core_matrix_ready) ? 1 : 0;
}

// ---- On-board UNO Q 8x13 LED matrix (Arduino_LED_Matrix) ----

// Simple letter shapes (S/D/G/R) + setup step numbers 1/2/3.

// S1
uint8_t CORE_SETUP1_LOGO[104] = {
  0,0,0,0,0,0,0,0,0,0,0,0,0,
  0,0,1,1,1,0,0,0,0,0,0,0,0,
  0,0,1,0,0,0,0,0,1,0,0,0,0,
  0,0,1,1,1,0,0,0,1,0,0,0,0,
  0,0,0,0,1,0,0,0,1,0,0,0,0,
  0,0,1,1,1,0,0,0,1,0,0,0,0,
  0,0,0,0,0,0,0,0,0,0,0,0,0,
  0,0,0,0,0,0,0,0,0,0,0,0,0
};

// S2
uint8_t CORE_SETUP2_LOGO[104] = {
  0,0,0,0,0,0,0,0,0,0,0,0,0,
  0,0,1,1,1,0,0,0,0,0,0,0,0,
  0,0,1,0,0,0,0,0,1,0,0,0,0,
  0,0,1,1,1,0,0,0,1,1,0,0,0,
  0,0,1,0,0,0,0,0,1,0,1,0,0,
  0,0,1,1,1,0,0,0,1,1,1,0,0,
  0,0,0,0,0,0,0,0,0,0,0,0,0,
  0,0,0,0,0,0,0,0,0,0,0,0,0
};

// S3
uint8_t CORE_SETUP3_LOGO[104] = {
  0,0,0,0,0,0,0,0,0,0,0,0,0,
  0,0,1,1,1,0,0,0,0,0,0,0,0,
  0,0,1,0,0,0,0,0,1,0,1,0,0,
  0,0,1,1,1,0,0,0,0,1,0,0,0,
  0,0,1,0,0,0,0,0,0,1,0,0,0,
  0,0,1,1,1,0,0,0,1,0,1,0,0,
  0,0,0,0,0,0,0,0,0,0,0,0,0,
  0,0,0,0,0,0,0,0,0,0,0,0,0
};

// D
uint8_t CORE_DETECT_LOGO[104] = {
  0,0,0,0,0,0,0,0,0,0,0,0,0,
  0,0,1,1,0,0,0,0,0,0,0,0,0,
  0,0,1,0,1,0,0,0,0,0,0,0,0,
  0,0,1,0,0,1,0,0,0,0,0,0,0,
  0,0,1,0,0,1,0,0,0,0,0,0,0,
  0,0,1,0,1,0,0,0,0,0,0,0,0,
  0,0,1,1,0,0,0,0,0,0,0,0,0,
  0,0,0,0,0,0,0,0,0,0,0,0,0
};

// G
uint8_t CORE_GRAB_LOGO[104] = {
  0,0,0,0,0,0,0,0,0,0,0,0,0,
  0,0,0,1,1,0,0,0,0,0,0,0,0,
  0,0,1,0,0,1,0,0,0,0,0,0,0,
  0,0,1,0,0,0,0,0,0,0,0,0,0,
  0,0,1,0,1,1,0,0,0,0,0,0,0,
  0,0,1,0,0,1,0,0,0,0,0,0,0,
  0,0,0,1,1,0,0,0,0,0,0,0,0,
  0,0,0,0,0,0,0,0,0,0,0,0,0
};

// R
uint8_t CORE_RELEASE_LOGO[104] = {
  0,0,0,0,0,0,0,0,0,0,0,0,0,
  0,0,1,1,1,0,0,0,0,0,0,0,0,
  0,0,1,0,0,1,0,0,0,0,0,0,0,
  0,0,1,0,0,1,0,0,0,0,0,0,0,
  0,0,1,1,1,0,0,0,0,0,0,0,0,
  0,0,1,0,1,0,0,0,0,0,0,0,0,
  0,0,1,0,0,1,0,0,0,0,0,0,0,
  0,0,0,0,0,0,0,0,0,0,0,0,0
};

// Error base pattern "ER" on the left, room for small digit on the right.
uint8_t CORE_ERROR1_LOGO[104] = {
  // ER1
  0,0,0,0,0,0,0,0,0,0,0,0,0,
  0,1,1,1,0,0,1,0,0,0,0,1,0,
  0,1,0,0,0,0,1,0,0,0,1,1,0,
  0,1,1,1,0,0,1,0,0,0,0,1,0,
  0,1,0,0,0,0,1,0,0,0,0,1,0,
  0,1,1,1,0,0,1,0,0,0,0,1,0,
  0,0,0,0,0,0,0,0,0,0,0,0,0,
  0,0,0,0,0,0,0,0,0,0,0,0,0
};

uint8_t CORE_ERROR2_LOGO[104] = {
  // ER2
  0,0,0,0,0,0,0,0,0,0,0,0,0,
  0,1,1,1,0,0,1,0,0,0,1,1,0,
  0,1,0,0,0,0,1,0,0,1,0,1,0,
  0,1,1,1,0,0,1,0,0,0,1,1,0,
  0,1,0,0,0,0,1,0,0,1,0,0,0,
  0,1,1,1,0,0,1,0,0,1,1,1,0,
  0,0,0,0,0,0,0,0,0,0,0,0,0,
  0,0,0,0,0,0,0,0,0,0,0,0,0
};

uint8_t CORE_ERROR3_LOGO[104] = {
  // ER3
  0,0,0,0,0,0,0,0,0,0,0,0,0,
  0,1,1,1,0,0,1,0,0,0,1,1,0,
  0,1,0,0,0,0,1,0,0,0,0,1,0,
  0,1,1,1,0,0,1,0,0,0,1,1,0,
  0,1,0,0,0,0,1,0,0,0,0,1,0,
  0,1,1,1,0,0,1,0,0,0,1,1,0,
  0,0,0,0,0,0,0,0,0,0,0,0,0,
  0,0,0,0,0,0,0,0,0,0,0,0,0
};

uint8_t CORE_ERROR4_LOGO[104] = {
  // ER4
  0,0,0,0,0,0,0,0,0,0,0,0,0,
  0,1,1,1,0,0,1,0,0,1,0,1,0,
  0,1,0,0,0,0,1,0,0,1,0,1,0,
  0,1,1,1,0,0,1,0,0,1,1,1,0,
  0,1,0,0,0,0,1,0,0,0,0,1,0,
  0,1,1,1,0,0,1,0,0,0,0,1,0,
  0,0,0,0,0,0,0,0,0,0,0,0,0,
  0,0,0,0,0,0,0,0,0,0,0,0,0
};

uint8_t CORE_ERROR5_LOGO[104] = {
  // ER5
  0,0,0,0,0,0,0,0,0,0,0,0,0,
  0,1,1,1,0,0,1,0,0,1,1,1,0,
  0,1,0,0,0,0,1,0,0,1,0,0,0,
  0,1,1,1,0,0,1,0,0,1,1,1,0,
  0,1,0,0,0,0,1,0,0,0,0,1,0,
  0,1,1,1,0,0,1,0,0,1,1,1,0,
  0,0,0,0,0,0,0,0,0,0,0,0,0,
  0,0,0,0,0,0,0,0,0,0,0,0,0
};

void _core_matrix_set_state(int state_code) {
  if (!core_matrix_ready) return;
  if (state_code == 0) {
    coreMatrix.draw(CORE_DETECT_LOGO);
    return;
  }
  if (state_code == 1) {
    coreMatrix.draw(CORE_GRAB_LOGO);
    return;
  }
  if (state_code == 2) {
    coreMatrix.draw(CORE_RELEASE_LOGO);
    return;
  }
  if (state_code == 3) {
    // Generic setup (if phase not specified).
    coreMatrix.draw(CORE_SETUP1_LOGO);
    return;
  }
}

int core_matrix_set_setup_step(int step) {
  if (!core_matrix_ready) return -1;
  if (step == 1) {
    coreMatrix.draw(CORE_SETUP1_LOGO);
    return 1;
  }
  if (step == 2) {
    coreMatrix.draw(CORE_SETUP2_LOGO);
    return 1;
  }
  if (step == 3) {
    coreMatrix.draw(CORE_SETUP3_LOGO);
    return 1;
  }
  return 0;
}

int core_matrix_set_error_code(int code) {
  if (!core_matrix_ready) return -1;
  if (code == 1) {
    coreMatrix.draw(CORE_ERROR1_LOGO);
    return 1;
  }
  if (code == 2) {
    coreMatrix.draw(CORE_ERROR2_LOGO);
    return 1;
  }
  if (code == 3) {
    coreMatrix.draw(CORE_ERROR3_LOGO);
    return 1;
  }
  if (code == 4) {
    coreMatrix.draw(CORE_ERROR4_LOGO);
    return 1;
  }
  if (code == 5) {
    coreMatrix.draw(CORE_ERROR5_LOGO);
    return 1;
  }
  return 0;
}

int core_matrix_clear() {
  if (!core_matrix_ready) return -1;
  uint8_t blank[104] = {0};
  coreMatrix.draw(blank);
  return 1;
}

int led_matrix_set_intensity(int level) {
  // Head matrix (ModulinoLEDMatrix) does not expose a brightness API in this project.
  // Intensity for the UNO Q onboard coreMatrix is not supported by Arduino_LED_Matrix
  // in this environment, so we only keep the RAM value for API compatibility.
  if (level < 0) level = 0;
  if (level > 15) level = 15;
  led_matrix_intensity = level;
  return 1;
}

int led_matrix_clear() {
  if (!head_matrix_ready) return -1;
  headMatrix.clear();
  return 1;
}

int led_matrix_set_state(int state_code) {
  // Always update on-board matrix if available.
  _core_matrix_set_state(state_code);

  head_state_code = state_code;
  _head_render_state(state_code, false);
  head_last_render_state = state_code;
  head_last_render_blink = false;
  return (head_matrix_ready || core_matrix_ready) ? 1 : -1;
}

void setup() {
  Bridge.begin();

  // Standard PWM servo on D9 (gripper) — start at 180° (closed)
  servo.attach(SERVO_PIN, 500, 2500);
  servo.writeMicroseconds(_angleToUs(lastServoAngle));  // 180 = closed

  // STS3215 serial bus on Serial (UNO Q side)
  Serial.begin(1000000);
  sts.pSerial = &Serial;

  // On-board LED matrix
  coreMatrix.begin();
  coreMatrix.setGrayscaleBits(1);
  core_matrix_ready = true;
  _core_matrix_set_state(3);  // setup state at boot

  // Head LED matrix (Modulino LED Matrix)
#if HAS_MODULINO_CORE
  Modulino.begin();
#endif
  delay(50);
  if (headMatrix.begin()) {
    head_matrix_ready = true;
    _head_render_state(3, false);
  } else {
    head_matrix_ready = false;
  }

  pinMode(PRESSURE_PIN_A0, INPUT);
  pinMode(PRESSURE_PIN_A1, INPUT);

  Bridge.provide_safe("move_servo", move_servo);
  Bridge.provide_safe("gripper_hold", gripper_hold);
  Bridge.provide_safe("read_pressure_a0", read_pressure_a0);
  Bridge.provide_safe("read_pressure_a1", read_pressure_a1);
  Bridge.provide_safe("sts_ping", sts_ping);
  Bridge.provide_safe("sts_read_pos", sts_read_pos);
  Bridge.provide_safe("sts_move_pos", sts_move_pos);
  Bridge.provide_safe("sts_torque_enable", sts_torque_enable);
  Bridge.provide_safe("led_matrix_available", led_matrix_available);
  Bridge.provide_safe("led_matrix_set_intensity", led_matrix_set_intensity);
  Bridge.provide_safe("led_matrix_clear", led_matrix_clear);
  Bridge.provide_safe("led_matrix_set_state", led_matrix_set_state);
  Bridge.provide_safe("core_matrix_set_setup_step", core_matrix_set_setup_step);
  Bridge.provide_safe("core_matrix_set_error_code", core_matrix_set_error_code);
  Bridge.provide_safe("core_matrix_clear", core_matrix_clear);
}

void loop() {
  _head_tick();
  // Yield to let RouterBridge and other tasks run reliably on Zephyr.
  delay(2);
}

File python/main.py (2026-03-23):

# SPDX-FileCopyrightText: Copyright (C) ARDUINO SRL (http://www.arduino.cc)
#
# SPDX-License-Identifier: MPL-2.0

from arduino.app_utils import App, Bridge
from arduino.app_bricks.video_objectdetection import VideoObjectDetection
from datetime import datetime, UTC
import time
import threading
import math
import os
import sys
from functools import partial


def _enable_unbuffered_console_and_file_log() -> None:
    """
    Best-effort: make prints visible in real time.
    Some launchers capture/buffer stdout; this forces flushing and also mirrors
    stdout/stderr to a local log file for debugging.
    """

    # 1) Force line-buffering (when supported) so lines appear immediately.
    try:
        sys.stdout.reconfigure(line_buffering=True)
    except Exception:
        pass
    try:
        sys.stderr.reconfigure(line_buffering=True)
    except Exception:
        pass

    # 2) Mirror stdout/stderr to a file in this project (useful when console is muted).
    log_path = os.environ.get("ROBOT_LOG_PATH") or os.path.join(
        os.path.dirname(__file__), "robot.log"
    )
    try:
        log_f = open(log_path, "a", encoding="utf-8", buffering=1)
    except Exception:
        return

    class _Tee:
        def __init__(self, a, b):
            self._a = a
            self._b = b
            self._at_line_start = True

        def write(self, s):
            if not s:
                return 0
            # Prepend timestamp at the start of each line.
            from datetime import datetime as _dt
            parts = s.split("\n")
            out_parts = []
            for i, part in enumerate(parts):
                if i > 0:
                    out_parts.append("\n")
                    self._at_line_start = True
                if part:
                    if self._at_line_start:
                        ts = _dt.now().strftime("%H:%M:%S.%f")[:-3]
                        out_parts.append(f"[{ts}] {part}")
                    else:
                        out_parts.append(part)
                    self._at_line_start = False
            stamped = "".join(out_parts)
            try:
                self._a.write(stamped)
            except Exception:
                pass
            try:
                self._b.write(stamped)
            except Exception:
                pass
            return len(s)

        def flush(self):
            try:
                self._a.flush()
            except Exception:
                pass
            try:
                self._b.flush()
            except Exception:
                pass

        def isatty(self):
            try:
                return bool(getattr(self._a, "isatty")())
            except Exception:
                return False

    sys.stdout = _Tee(sys.stdout, log_f)
    sys.stderr = _Tee(sys.stderr, log_f)


_enable_unbuffered_console_and_file_log()

# Ensure every print flushes by default (helps with buffered stdout).
print = partial(print, flush=True)

# ID dei servo STS3215 (solo 4 presenti sul bus)
STS_SERVO_IDS = (1, 2, 3, 4)
STS_CHECK_IDS = STS_SERVO_IDS
STS_STARTUP_DELAY_SEC = 6.0  # Attesa prima del check (Bridge/MCU/servo bus devono essere pronti)

# Bridge calls can time out during early startup or transient USB/serial hiccups.
BRIDGE_CALL_RETRIES = 3
BRIDGE_CALL_RETRY_DELAY_SEC = 0.25
BRIDGE_RESULT_TIMEOUT_SEC = 5.0  # Prevent deadlock if MCU never responds to .result()



def _print_sts_servo_info():
    """Stampa a console ping e posizione per ogni ID STS3215 (per check)."""
    print("[STS3215] Check servo (ping + posizione):\n")
    all_ok = True
    for sid in STS_CHECK_IDS:
        print(f"[STS3215] checking id={sid} ...")
        ok = sts_ping(sid)
        pos = sts_read_pos(sid)
        pos_str = str(pos) if pos is not None else "—"
        status = "OK" if ok else "NO"
        all_ok = all_ok and ok and pos is not None
        print(f"  ID={sid}  ping={status}  pos={pos_str}")
    print()
    return all_ok


def _startup_sts_check():
    """Esegue il check STS dopo un breve delay (Bridge deve essere connesso)."""
    try:
        time.sleep(STS_STARTUP_DELAY_SEC)
        # Initialize LED matrix now that Bridge is ready.
        try:
            led_matrix_set_intensity(_led_matrix_intensity)
            led_matrix_set_state_name(STATE_SETUP)
        except Exception:
            pass
        # Clear indication: now it's safe to start setup and move the robot by hand.
        core_matrix_set_setup_step(1)
        print("[SETUP] Move robot to HOME, then hold still 5s.")
        print(f"[SETUP] Then move robot to each of the {GRAB_SLOT_COUNT_MAX} slots, holding still 5s each.")
        # Ready for setup: nod + open gripper slightly
        _set_sts_torque_enabled(True)
        _setup_nod_servo4()
        _set_sts_torque_enabled(False)
        _set_gripper_setup_open_free()
        all_ok = _print_sts_servo_info()
        if not all_ok:
            core_matrix_set_error_code(ERR_SETUP_POSE_UNAVAILABLE)
            print(
                "[SETUP][ERROR] One or more STS3215 servos did not respond (check wiring/half-duplex adapter/IDs)."
            )
        print("[SETUP] READY: you can move the arm now.")
    except Exception as e:
        print(f"[STS3215] startup check failed: {e}")
    finally:
        _startup_check_done.set()


# State machine: setup -> detect -> (face) -> grab -> delivery -> (face) -> release -> detect
STATE_SETUP = "setup"
STATE_DETECT = "detect"
STATE_GRAB = "grab"
STATE_DELIVERY = "delivery"
STATE_RELEASE = "release"

# Gripper servo angles (adjust if your servo is reversed)
GRIPPER_OPEN_ANGLE = 150  # fully open
GRIPPER_CLOSED_ANGLE = 180  # fully closed (max grip)
GRIPPER_GRAB_PREOPEN_ANGLE = 165  # narrow opening (~2cm) to grab a pen
GRIPPER_GRAB_PRE_CLOSE_ANGLE = 25  # micro-close after reaching gadget point
GRIPPER_GRAB_PRE_CLOSE_WAIT_SEC = 0.35
GRIPPER_SETUP_OPEN_ANGLE = GRIPPER_GRAB_PREOPEN_ANGLE  # same opening as pre-grab

GRAB_OPEN_WAIT_SEC = 1.0
GRAB_CLOSE_WAIT_SEC = 1.0
GRAB_WAIT_BEFORE_HOME_SEC = 15.0
GRAB_SETTLE_BEFORE_CLOSE_SEC = 2.0
GRAB_APPROACH_SPEED = 700
GRAB_APPROACH_ACC = 20
GRAB_RETURN_SPEED = 800
GRAB_RETURN_ACC = 25
RELEASE_OPEN_WAIT_SEC = 3.0
DELIVERY_HEART_SEC = 3.0  # show heart eyes then release pen
DELIVERY_POST_RELEASE_HOME_SEC = 5.0  # wait at home before returning to idle

DELIVERY_SPEED = 650
DELIVERY_ACC = 18

# Posizione "home" del braccio STS3215 (RAM-only session).
HOME_DEFAULT_POSITION = {
    1: 2048,
    2: 2048,
    3: 2048,
    4: 2048,
}
HOME_POSITION = dict(HOME_DEFAULT_POSITION)
HOME_MOVE_SPEED = 900
HOME_MOVE_ACC = 30
HOME_SETTLE_SEC = 1.2

# Posizioni di tutti gli slot (RAM-only session, catturate durante setup).
SLOT_POSITIONS: list[dict[int, int]] = []

# Setup automatico: fermo per N secondi -> salva posizione.
SETUP_STABLE_SECONDS = 5.0
# Threshold for detecting "manual movement" while torque is OFF.
# Too low can trigger on micro-movement / sensor noise during settling.
SETUP_MOVEMENT_THRESHOLD = 40
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

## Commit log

2026-03-03 Add servo control functionality with UI sliders
    - Implemented servo slider initialization and control in app.js.
    - Added HTML structure for servo sliders in index.html.
    - Enhanced CSS for servo section styling.
    - Introduced API endpoints in main.py for fetching and moving servo positions.
    - Added startup check for servo positions on application launch.
2026-03-13 Enhance state management and UI for robotic arm control
    - Added state timeline feature in app.js to visualize and control states (setup, detect, grab, release).
    - Updated HTML to include state timeline buttons and improved state display.
    - Enhanced CSS for state timeline and button styling.
    - Introduced new API endpoints in main.py for managing home and first slot positions.
    - Improved feedback messages for user guidance during operation.
2026-03-13 Refactor robotic arm control logic and improve performance
    - Reduced polling intervals for pressure, state, and servo position updates in app.js for more responsive behavior.
    - Enhanced startup instructions in main.py for clearer user guidance during setup.
    - Introduced new functions for capturing and managing servo poses, improving the setup phase handling.
    - Updated the Arduino sketch to support new Modulino core features and improved LED matrix handling.
    - Added gripper control functionality to manage servo attachment and detachment.
2026-03-13 Implement gripper control enhancements in robotic arm workflow
    - Added logic to keep the object clamped until the arm returns to the home position.
    - Introduced delays for user pickup time and gripper state transitions to improve operation flow.
    - Updated the state machine to reflect changes in gripper handling during the grab process.
2026-03-16 Enhance robotic arm setup and error handling
    - Added support for capturing a second slot position during the setup phase to improve object placement accuracy.
    - Introduced error codes for better diagnostics related to matrix availability and setup pose issues.
    - Updated gripper control parameters for smoother operation during the grab and return processes.
    - Enhanced LED matrix functionality to provide visual feedback for different states and errors during operation.
    [main.py, sketch.ino]
2026-03-18 Remove LED matrix intensity controls and related UI elements
    - Eliminated matrix intensity slider and value display from the HTML and JavaScript files to simplify the interface.
    - Updated the refresh function to remove references to intensity handling, streamlining LED matrix status updates.
    - Adjusted the Python code to ensure compatibility with the changes in the LED matrix functionality.
2026-03-18 Refactor robotic arm setup and error handling
    - Removed Web UI integration to streamline the robotic arm's functionality, focusing on face detection and core logic.
    - Enhanced servo status checks during startup to ensure all servos respond correctly, with error handling for unresponsive servos.
    - Adjusted movement detection thresholds and added grace periods to improve setup stability and prevent false triggers.
    - Updated the Arduino sketch to clarify LED matrix intensity handling, maintaining compatibility without actual intensity control.
    [main.py, sketch.ino]
2026-03-19 Enhance robotic arm functionality and visual feedback
    - Implemented timestamped logging for console output to improve debugging and monitoring.
    - Updated state machine to include a new delivery state, enhancing the arm's operational flow.
    - Adjusted gripper angles for improved object handling and added new parameters for better control during delivery.
    - Introduced heart-shaped eyes animation on the LED matrix during the delivery phase for visual feedback.
    - Enhanced setup phase logic to stabilize pose detection and added blinking indicators for user guidance.
    [main.py, sketch.ino]
2026-03-23 Remove legacy UI and JavaScript files for robotic arm control
    - Deleted app.js, index.html, and style.css to streamline the project and focus on core functionality.
    - This cleanup removes unnecessary web interface components, aligning with recent refactoring efforts to enhance the robotic arm's performance and usability.
2026-03-23 Refactor robotic arm setup phase for improved slot handling
    - Updated setup logic to capture positions for multiple slots dynamically, replacing the previous fixed first and second slot approach.
    - Enhanced user instructions during setup to clarify the process for moving to each slot.
    - Removed legacy variables related to first and second slots, streamlining the code for better maintainability.
    - Adjusted console output to provide clearer feedback on captured slot positions.
    [main.py, sketch.ino]
2026-03-30 Add 3D model for Arduino robot gadget
    [arduino_robot_gadget_3d_model.3mf, arduino_support_shield.stl, base_cover.stl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]
2026-03-30 Add USB Camera to Bill of Materials in README
2026-03-30 Clarify pin scheme details for STS3215 bus and Modulino LED Matrix in README
2026-04-01 add exported arduino uno app lab app
2026-04-03 Add servo ID change functionality for SCServo
    - Implemented a new sketch to change the ID of SCServo motors.
2026-04-12 Implement smooth servo movement with gradual angle adjustments
2026-04-12 update arduino app
2026-04-17 Update assembly tutorial link and image in README
2026-04-17 Revert "update readme"
    This reverts commit c829bb8294cde2dde193081b7bddad22a9aad44d.
    [main.py]
